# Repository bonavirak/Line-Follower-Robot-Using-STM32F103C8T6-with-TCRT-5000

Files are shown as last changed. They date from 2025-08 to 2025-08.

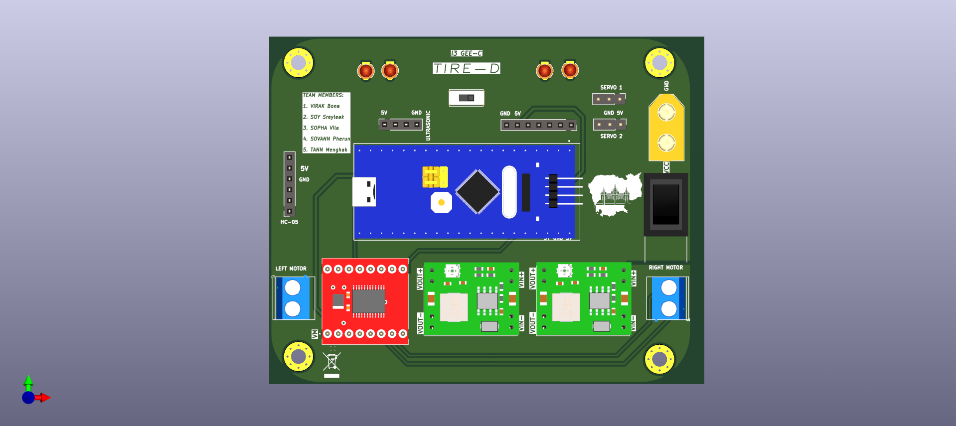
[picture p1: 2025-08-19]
LineFollowerPCB/fun.png

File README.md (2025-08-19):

# Line Follower Robot with STM32F103C8T6 and TCRT5000

This Line Follower Robot, winner of Line Follwer Robot Competition 2025, was designed and developed by Bona Virak. The project uses an STM32F103C8T6 microcontroller, TCRT5000 5-way sensors, HC-05 Bluetooth module, TB6612FNG motor driver, and N20 motors (1000 RPM). It features two modes: Auto (PID-based line following with Case 0/Case 1 logic) and Manual (Bluetooth RC control via app).

## Credits
- **Author**: [Bona Virak](https://github.com/bonavirak) - Sole developer of the code, PCB design, and implementation.
- **Team**: Tire-d - Acknowledged for participation in Line Follwer Robot Competition 2025, with minimal contributions.

## Features
- C-based firmware with PID control for auto mode line following.
- Manual mode for Bluetooth RC car control via HC-05.
- PCB design (schematics, Gerber files, BOM) optimized for STM32 integration.
- Case-based navigation (Case 0 for straight paths, Case 1 for turns) in auto mode.

## Setup
### Hardware
1. **Components**:
   - STM32F103C8T6 microcontroller
   - TCRT5000 5-way sensor array
   - HC-05 Bluetooth module
   - TB6612FNG motor driver
   - 2x N20 motors (1000 RPM)
   - Power supply (e.g., 11.1V LiPo battery)
2. **Schematic**:
   - See schematic: 
3. **Wiring**:
- **Connect TCRT5000 Sensors to STM32**:
  - Pins: **PA0-PA4** 
- **Link HC-05 TX/RX to STM32**:
  - USART1: **PA9/PA10** (TX/RX) 
- **Attach TB6612FNG PWM/GPIO Pins to STM32**:
  - PWMA: **PB7**  (TIM4 CH2)
  - PWMB: **PB6**  (TIM4 CH1)
  - AI1: **PB12** 
  - AI2: **PB13** 
  - BI1: **PB14** 
  - BI2: **PB15** 
  - STBY: **PB1** 
  - VCC: **3.3V** 
- **Add Servo to STM32**:
  - PWM: **PB4** (TIM3 CH1) 
- **Wire N20 Motors to TB6612FNG Outputs**:
  - Power: **11.1V LiPo** 
- **Refer to Detailed Pin Assignments**:
  - Check out the epic diagram! 
   Pin Assignments

### Software
1. **Requirements**:
   - STM32CubeIDE for compiling C code.
   - ST-Link/V2 for flashing.
   - Bluetooth RC app (e.g., "Bluetooth RC Controller" on Android) for manual mode.
2. **Steps**:
   - Clone: git clone: https://github.com/bonavirak/STM32F103C8T6-Line-Follower-Robot-TCRT5000.git.
   - Open `/code/` in STM32CubeIDE.
   - Configure PID in `pid.c` (e.g., Kp=0.5, Ki=0.1, Kd=0.05) for auto mode.
   - Build/flash code to STM32F103C8T6 using ST-Link.
3. **Auto Mode**:
   - Test Case 0/Case 1 on sample map 
4. **Manual Mode**:
   - Pair HC-05 with Bluetooth RC app (default PIN: 1234 or 0000).
   - Use app to control motors (forward, backward, left, right).

## Demo
Watch the robot in action:
- **Video**: [Video demo will be added soon!]
- **Images**: [Soon!]
- **Description**: Auto mode uses PID control for line following (Case 0 for straight, Case 1 for turns). Manual mode allows RC car control via Bluetooth app, demonstrated in Line Follwer Robot Competition 2025 winning run.

## License
Licensed under the MIT License. See [LICENSE](LICENSE) for details.

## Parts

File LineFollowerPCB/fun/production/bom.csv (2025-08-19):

Designator | Footprint | Quantity | Value | LCSC Part #
C1, C3 | 0603 | 2 | 0.1uF
C2, C4 | 0603 | 2 | 10uF
D2, D3, D4, D5 | LED_D3.0mm | 4 | LED
H1, H2, H3, H4 | MountingHole_3.5mm_Pad_Via | 4 | MountingHole
HC1 | PinSocket_1x06_P2.54mm_Vertical | 1 | Conn_01x06_Female
J1 | AMASS_XT60-M_1x02_P7.20mm_Vertical | 1 | Screw_Terminal_01x02
J10, J6 | PinSocket_1x02_P2.54mm_Vertical | 2 | VIN+
J11, J8 | PinSocket_1x02_P2.54mm_Vertical | 2 | VIN-
J12, J7 | PinSocket_1x02_P2.54mm_Vertical | 2 | VOUT+
J13, J9 | PinSocket_1x02_P2.54mm_Vertical | 2 | VOUT-
J2 | TerminalBlock_Phoenix_MKDS-1,5-2_1x02_P5.00mm_Horizontal-(Large) | 1 | Left_Motor
J3 | TerminalBlock_Phoenix_MKDS-1,5-2_1x02_P5.00mm_Horizontal-(Large) | 1 | Right_Motor
J4 | PinSocket_1x04_P2.54mm_Vertical | 1 | ULTRASONIC
R2, R3, R4, R5 | 0603 | 4 | 220
SERVO1, SERVO2 | PinHeader_1x03_P2.54mm_Vertical | 2 | ~
SW1 | BarrelJack_SwitchcraftConxall_RAPC10U_Horizontal | 1 | SW_SPST
SW2 | PinHeader_1x03_P2.54mm_Vertical | 1 | SW_SPDT
TCRT1 | PinSocket_1x07_P2.54mm_Vertical | 1 | Conn_01x07_Female
U1 | MODULE_ROB-14450 | 1 | ROB-14450
U2 | STM32F103C8T6 | 1 | ZC323000

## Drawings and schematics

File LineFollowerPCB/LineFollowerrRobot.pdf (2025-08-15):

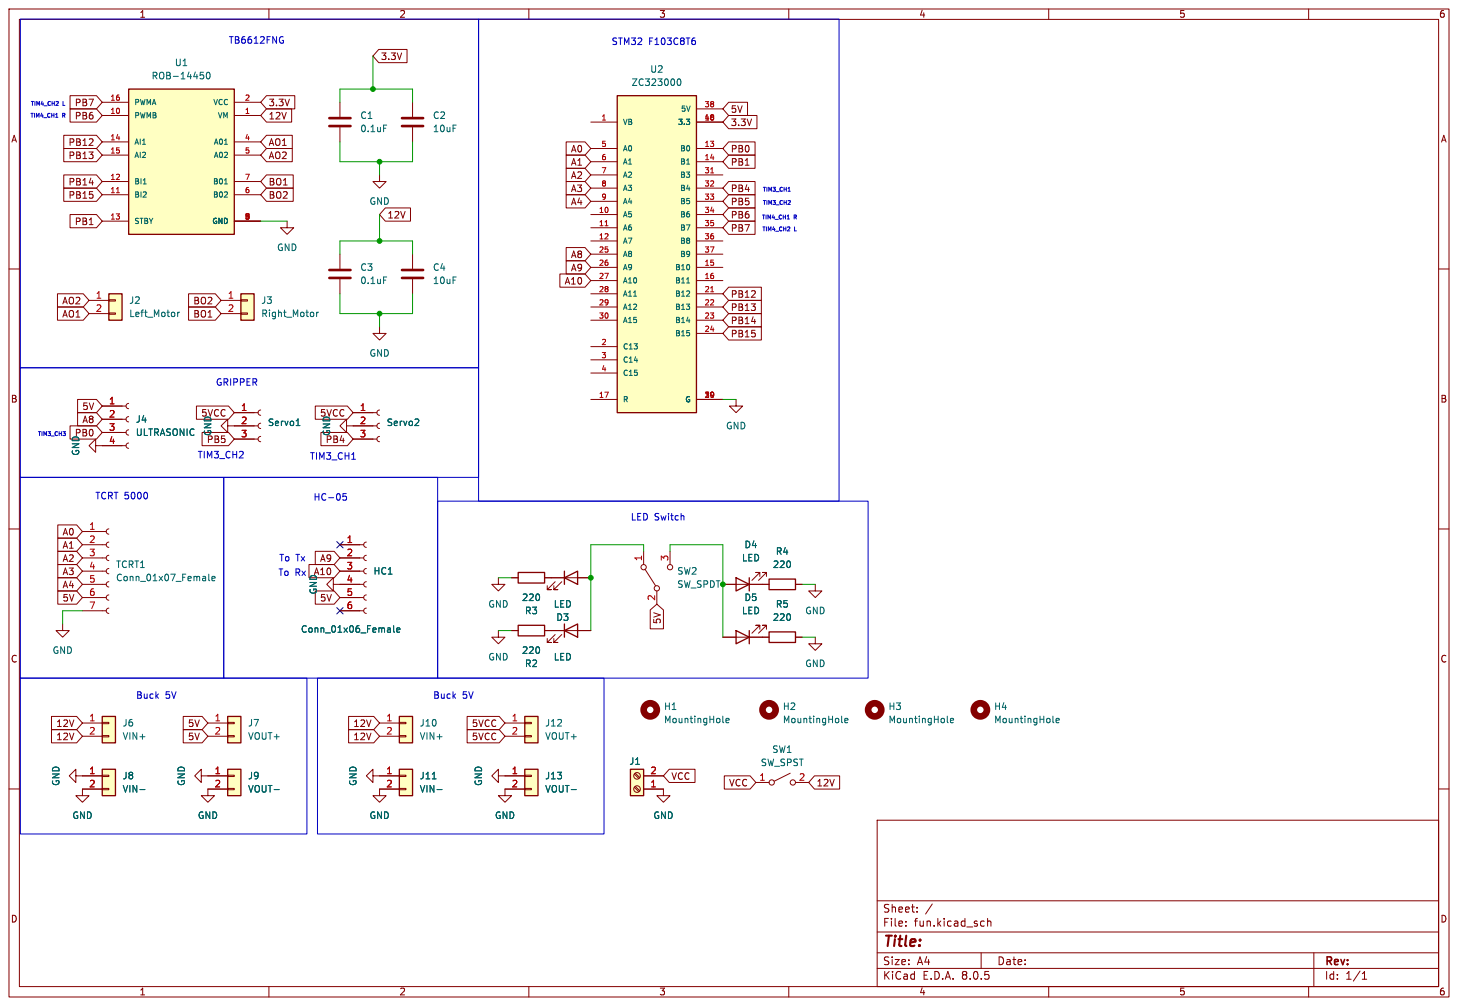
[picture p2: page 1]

LED
Id: 1/1 Title: File: fun.kicad_sch Sheet: / R3


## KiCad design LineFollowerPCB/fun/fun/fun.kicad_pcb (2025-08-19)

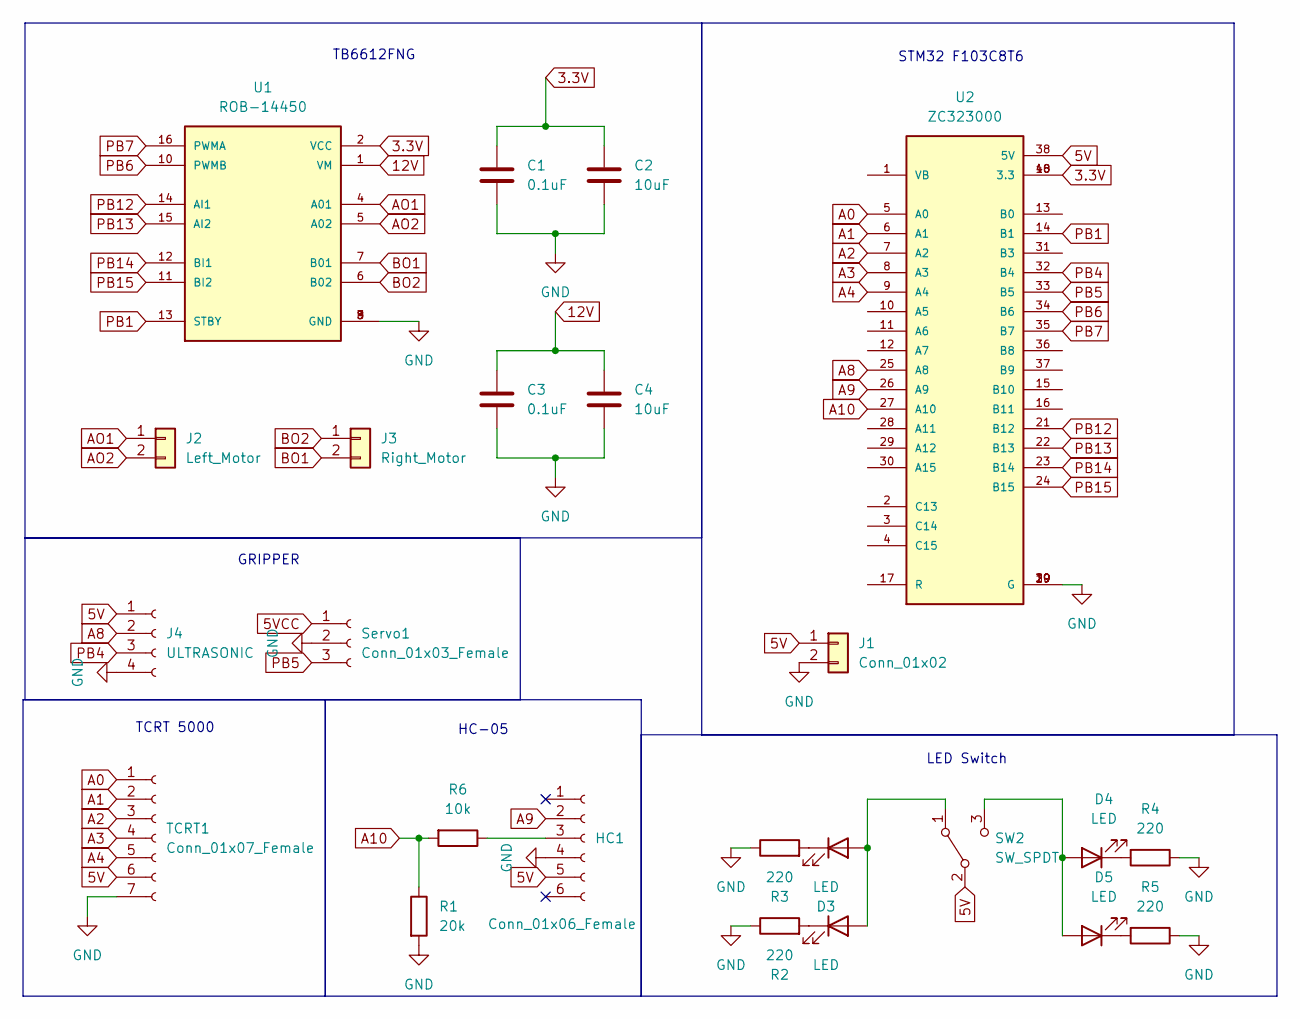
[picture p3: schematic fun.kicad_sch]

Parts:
C1, C3: 0.1uF; C_0603_1608Metric
C2, C4: 10uF; C_0603_1608Metric
D2, D3, D4, D5: LED; LED_D3.0mm
HC1: Conn_01x06_Female; PinSocket_1x06_P2.54mm_Vertical
J1: Conn_01x02; PinSocket_1x02_P2.54mm_Vertical
J2: Left_Motor; PinSocket_1x02_P2.54mm_Vertical
J3: Right_Motor; PinSocket_1x02_P2.54mm_Vertical
J4: ULTRASONIC; PinSocket_1x04_P2.54mm_Vertical
R1: 20k; R_0201_0603Metric
R2, R3, R4, R5: 220; R_0201_0603Metric
R6: 10k; R_0201_0603Metric
SW2: SW_SPDT; PinHeader_1x03_P2.54mm_Vertical
Servo1: Conn_01x03_Female; PinSocket_1x03_P2.54mm_Vertical
TCRT1: Conn_01x07_Female; PinSocket_1x07_P2.54mm_Vertical
U1: ROB-14450; MODULE_ROB-14450; PARTREV 11-13-17
U2: ZC323000; STM32F103C8T6; PARTREV N/A

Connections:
3.3V: C1.1, C2.1, U1.2 (VCC), U2.18 (3.3), U2.40 (3.3)
5V: HC1.5, J1.1, J4.1, SW2.2 (B), TCRT1.6, U2.38 (5V)
5VCC: Servo1.1
12V: C3.1, C4.1, U1.1 (VM)
A0: TCRT1.1, U2.5 (A0)
A1: TCRT1.2, U2.6 (A1)
A2: TCRT1.3, U2.7 (A2)
A3: TCRT1.4, U2.8 (A3)
A4: TCRT1.5, U2.9 (A4)
A8: J4.2, U2.25 (A8)
A9: HC1.2, U2.26 (A9)
A10: R1.1, R6.2, U2.27 (A10)
AO1: J2.1, U1.4 (A01)
AO2: J2.2, U1.5 (A02)
BO1: J3.2, U1.7 (B01)
BO2: J3.1, U1.6 (B02)
GND: C1.2, C2.2, C3.2, C4.2, HC1.4, J1.2, J4.4, R1.2, R2.1, R3.1, R4.1, R5.1, Servo1.2, TCRT1.7, U1.3 (GND), U1.8 (GND), U1.9 (GND), U2.19 (G), U2.20 (G), U2.39 (G)
unnamed: D2.2 (A), D3.2 (A), SW2.1 (A)
unnamed: D2.1 (K), R2.2
unnamed: D3.1 (K), R3.2
unnamed: D4.2 (A), D5.2 (A), SW2.3 (C)
unnamed: D4.1 (K), R4.2
unnamed: D5.1 (K), R5.2
unnamed: HC1.3, R6.1
PB1: U1.13 (STBY), U2.14 (B1)
PB4: J4.3, U2.32 (B4)
PB5: Servo1.3, U2.33 (B5)
PB6: U1.10 (PWMB), U2.34 (B6)
PB7: U1.16 (PWMA), U2.35 (B7)
PB12: U1.14 (AI1), U2.21 (B12)
PB13: U1.15 (AI2), U2.22 (B13)
PB14: U1.12 (BI1), U2.23 (B14)
PB15: U1.11 (BI2), U2.24 (B15)

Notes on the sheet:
GRIPPER
LED Switch
HC-05
TB6612FNG
STM32 F103C8T6
TCRT 5000

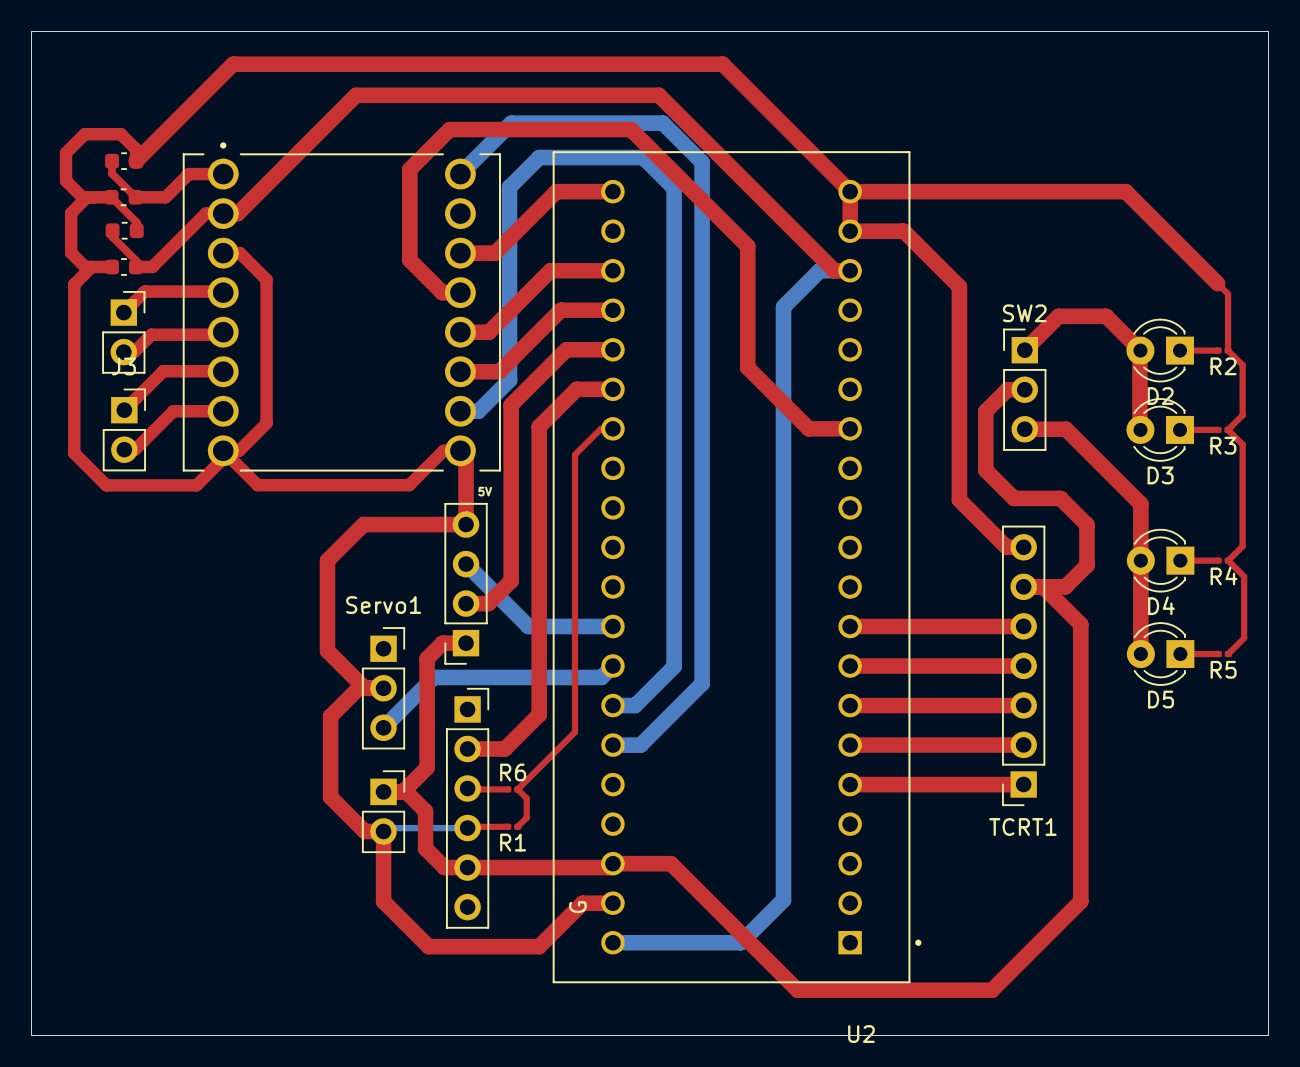
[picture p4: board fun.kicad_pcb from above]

Board: 2 copper layers, 79.5 x 64.5 mm, 24 parts (0 on the bottom side), 32 nets.

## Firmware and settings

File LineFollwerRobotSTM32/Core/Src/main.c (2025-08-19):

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
/* Includes ------------------------------------------------------------------*/
#include "main.h"

/* USER CODE BEGIN Includes */
#include <math.h>

/* USER CODE END Includes */

/* USER CODE BEGIN PD */
#define SENSOR_COUNT 5
#define MAX_SPEED 100    // Maximum speed
/* USER CODE END PD */

TIM_HandleTypeDef htim2;
TIM_HandleTypeDef htim3;
TIM_HandleTypeDef htim4;

UART_HandleTypeDef huart1;

/* USER CODE BEGIN PV */
int weights[5] = {-4, -2, 0, 2, 4}; // Define weights (in mm) for 5 sensors: left to right
float Kp = 2.5;                     // Proportional gain
float Ki = 0.001;                     // Integral gain
float Kd = 0.5;                    // Derivative gain
float dt = 0.005;                   // Time delta (seconds) — adjust to your system
float d = 10.0;                     // Distance between position readings (in mm)
float previous_error = 0;           // Previous error for derivative control
float integral = 0;                 // Accumulated error for integral control
float previous_position = 0;        // Previous position for heading angle
int intersection_count=0;
int grab_count=0;
int has_grabbed = 0; // Global flag to track if grab has occurred
int current_case = 0; // 0 = Case 0, 1 = Case 1, 2 = Case 2, etc.
int sensor_count = 0; // Count how many times all 5 sensors are detected in Case 1

uint8_t sensor_values[SENSOR_COUNT]; // Array to store sensor readings

float x =0;//lateral position
float u =0; //control output
int pwmL =0;
int pwmR=0;
int basespeed=0;

int j=0; // Line-loss

// UART-related variables
uint8_t rx_data;         // Received UART data
uint8_t last_command = 0;// Last received command

uint8_t uto = 'U';       // Mode control: 'U' for auto, 'u' for manual
char grip = 0;           // Gripper state: 'W' for close, 'w' for open
int speed_level = 7;     // Speed level (0-9) for manual mode

static int case1_delay_count = 0;
static int case2_stopped = 0;
static int case2_ignore_count = 0;
static int case2_post_stop_state = 0;
static int case2_post_action_count = 0;
static int case3_has_grabbed = 0;
static int turn_state = 0;
static int turn_count = 0;
static int case3_stopped = 0;
static int case3_ignore_count = 0;
static int case3_post_stop_state = 0;
static int case3_post_action_count = 0;

int caseF_active = 0;     // Flag to track if CaseF is active
int caseF_end_condition = 0; // Flag to track when CaseF should end

// New global variables for Case0 forward push
int case0_initial_push_count = 0; // Counter for initial forward push in Case0
int case0_initial_push_done = 0;  // Flag to track if initial push is complete in Case0

// New global variable for Case1 forward push
int case1_push_after_grab_done = 0; // Flag to track if forward push after grab is done

// New global variable for Case3 forward push
int case3_push_after_grab_count = 0; // Counter for forward push after grab in Case3

int case2_reset_active = 0; // Flag to track if Case2Reset is active


/* USER CODE END PV */

void SystemClock_Config(void);
static void MX_GPIO_Init(void);
static void MX_TIM4_Init(void);
static void MX_USART1_UART_Init(void);
static void MX_TIM3_Init(void);
static void MX_TIM2_Init(void);
/* USER CODE BEGIN PFP */
void set_left_motor(int speed);
void set_right_motor(int speed);
void read_sensors();
float compute_position();
float compute_pid(float error);
float compute_heading(float x_now);
void Set_Servo_Angle(uint8_t angle);
void motor_ctr(int speedL, int speedR);
void followLine(void);
void followLine_Case0(void);
void followLine_Case1(void);
void followLine_Case2(void);
void followLine_Case3(void);
/* USER CODE END PFP */

/* USER CODE BEGIN 0 */
void Set_Servo_Angle(uint8_t angle)
{
  // Map 0–180° to 500–2500us (pulse width in timer counts)
  uint16_t pulse_width = 500 + ((angle * 2000) / 180);
  __HAL_TIM_SET_COMPARE(&htim3, TIM_CHANNEL_1, pulse_width);  // Set PWM pulse width
}

/* USER CODE END 0 */

/**
  * @brief  The application entry point.
  * @retval int
  */
int main(void)
{

  /* MCU Configuration--------------------------------------------------------*/

  /* Reset of all peripherals, Initializes the Flash interface and the Systick. */
  HAL_Init();

  /* Configure the system clock */
  SystemClock_Config();

  /* Initialize all configured peripherals */
  MX_GPIO_Init();
  MX_TIM4_Init();
  MX_USART1_UART_Init();
  MX_TIM3_Init();
  MX_TIM2_Init();
  /* USER CODE BEGIN 2 */
  HAL_TIM_PWM_Start(&htim4, TIM_CHANNEL_1);
  HAL_TIM_PWM_Start(&htim4, TIM_CHANNEL_2);
  HAL_TIM_PWM_Start(&htim3, TIM_CHANNEL_1); // Start PWM for servo

  HAL_TIM_Base_Start_IT(&htim2);
  HAL_UART_Receive_IT(&huart1, &rx_data, 1); // Enable UART interrupt
  HAL_GPIO_WritePin(GPIOB, GPIO_PIN_1, 1);
  /* USER CODE END 2 */

  /* Infinite loop */
  /* USER CODE BEGIN WHILE */
  while (1)
  {
    /* USER CODE END WHILE */

    /* USER CODE BEGIN 3 */
  }
  /* USER CODE END 3 */
}

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
/* USER CODE BEGIN 4 */
/**
  * @brief Set speed and direction for the left motor
  * @param speed: Speed value (-95 to 95). Positive for forward, negative for backward.
  * @retval None
  */
void set_left_motor(int speed)
{
  speed = (speed > MAX_SPEED) ? MAX_SPEED : (speed < -MAX_SPEED/2) ? -MAX_SPEED/2 : speed;
  TIM4->CCR2 = (speed >= 0) ? (uint32_t)speed : (uint32_t)(-speed);
  HAL_GPIO_WritePin(GPIOB, GPIO_PIN_12, (speed > 0) ? GPIO_PIN_SET : GPIO_PIN_RESET);
  HAL_GPIO_WritePin(GPIOB, GPIO_PIN_13, (speed < 0) ? GPIO_PIN_SET : GPIO_PIN_RESET);
}

/**
  * @brief Set speed and direction for the right motor
  * @param speed: Speed value (-95 to 95). Positive for forward, negative for backward.
  * @retval None
  */
void set_right_motor(int speed)
{
  speed = (speed > MAX_SPEED) ? MAX_SPEED : (speed < -MAX_SPEED/2) ? -MAX_SPEED/2 : speed;
  TIM4->CCR1 = (speed >= 0) ? (uint32_t)speed : (uint32_t)(-speed);
  HAL_GPIO_WritePin(GPIOB, GPIO_PIN_14, (speed > 0) ? GPIO_PIN_SET : GPIO_PIN_RESET);
  HAL_GPIO_WritePin(GPIOB, GPIO_PIN_15, (speed < 0) ? GPIO_PIN_SET : GPIO_PIN_RESET);
}

void motor_ctr(int speedL, int speedR)
{
  set_right_motor(speedR);
  set_left_motor(speedL);
}

/**
  * @brief Read sensor states
  * @retval None
  */
void read_sensors(void)
{
  sensor_values[0] = !HAL_GPIO_ReadPin(GPIOA, GPIO_PIN_0);
  sensor_values[1] = !HAL_GPIO_ReadPin(GPIOA, GPIO_PIN_1);
  sensor_values[2] = !HAL_GPIO_ReadPin(GPIOA, GPIO_PIN_2);
  sensor_values[3] = !HAL_GPIO_ReadPin(GPIOA, GPIO_PIN_3);
  sensor_values[4] = !HAL_GPIO_ReadPin(GPIOA, GPIO_PIN_4);

  if (sensor_values[0] == 1) {
    j = 1;
  }
  else if (sensor_values[4] == 1) {
    j = 2;
  }

  if (j == 1) {
    sensor_values[0] = 1;
  }
  else if (j == 2) {
    sensor_values[4] = 1;
  }
  if (sensor_values[1] == 1 || sensor_values[2] == 1 || sensor_values[3] == 1) {
    j = 0;
  }
}

/**
  * @brief Compute lateral position
  * @retval float: Position in mm
  */
float compute_position()
{
  int sum_s = 0;
  int weighted_sum = 0;

  for (int i = 0; i < 5; i++) {
    sum_s += sensor_values[i];
    weighted_sum += sensor_values[i] * weights[i];
  }

  if (sum_s == 0)
    return 0.0; // No line detected, assume center or trigger fail-safe

  return (float)weighted_sum / sum_s;
}

/**
  * @brief Compute PID control output
  * @param error: Current error
  * @retval float: PID control output
  */
float compute_pid(float error)
{
  integral += error * dt;
  float derivative = (error - previous_error) / dt;
  float output = Kp * error + Ki * integral + Kd * derivative;
  previous_error = error;
  return output;
}

/**
  * @brief Compute heading angle
  * @param x_now: Current position
  * @retval float: Heading angle in radians
  */
float compute_heading(float x_now)
{
  float Q = (x_now - previous_position) / d;
  previous_position = x_now;
  return Q; // in radians (approximation)
}

void followLine(void)
{
  x = compute_position();
  u = compute_pid(x);
  if (fabs(x) < 1) {
    basespeed = 55;
  }
  else if (fabs(x) <= 2) {
    basespeed = 40;
  }
  else if (fabs(x) <= 4) {
    basespeed = 20;
  }
  pwmL = basespeed + u;
  pwmR = basespeed - u;
  motor_ctr(pwmL, pwmR);
}

void followLine_Case0(void)
{


	Set_Servo_Angle(40);

	// Step 2: Initial forward push for 200ms (40 cycles at 5ms)
	    if (!case0_initial_push_done) {
	        pwmL = 50; // Fixed speed for forward push
	        pwmR = 50;
	        motor_ctr(pwmL, pwmR);
	        case0_initial_push_count++;
	        if (case0_initial_push_count >= 40) { // 200ms / 5ms = 40 cycles
	            case0_initial_push_done = 1; // Mark push as complete
	            case0_initial_push_count = 0; // Reset counter for potential reuse
	        }
	        return; // Exit function until push is complete
	    }

  x = compute_position();
  u = compute_pid(x);
  if (fabs(x) < 1) {
    basespeed = 55;
  } else if (fabs(x) <= 2) {
    basespeed = 37;
  } else if (fabs(x) <= 4) {
    basespeed = 25
    		;
  }

  int sensor_sum = sensor_values[0] + sensor_values[1] + sensor_values[2] + sensor_values[3] + sensor_values[4];
  if (!has_grabbed) {
    if (sensor_values[0] == 1 && sensor_values[1] == 1 && sensor_values[2] == 1 && sensor_values[3] == 1) {
      Set_Servo_Angle(0); // Grab to 0°
      has_grabbed = 1;    // Prevent further servo commands
      current_case = 1;
    } else if (sensor_values[4] == 1 && sensor_values[3] == 1 && sensor_values[2] == 1 && sensor_values[1] == 1) {
      Set_Servo_Angle(0); // Grab to 0°
      has_grabbed = 1;    // Prevent further servo commands
      current_case = 1;
    } else if (sensor_sum == 5 && sensor_values[2] == 1) { // Ensure center sensor is off too
      Set_Servo_Angle(0); // Grab to 0°
      has_grabbed = 1;    // Prevent further servo commands
      current_case = 1;
    }
  }

  pwmL = basespeed + u;
  pwmR = basespeed - u;
  motor_ctr(pwmL, pwmR);
}

void followLine_Case1(void)
{

  // Set new PID values for Case 1
  Kp = 15;
  Ki = 0.0;
  Kd = 0.0;
  // Reset PID state
  integral = 0;
  previous_error = 0;

  // Step 1: Forward push for 200ms (40 cycles at 5ms) after grabbing
      if (!case1_push_after_grab_done) {
          if (case1_delay_count < 110) {
              pwmL = 30; // Fixed speed for forward push
              pwmR = 30;
              motor_ctr(pwmL, pwmR);
              case1_delay_count++;
              return; // Exit until push is complete
          } else {
              case1_push_after_grab_done = 1; // Mark push as complete
              case1_delay_count = 0; // Reset counter for next phase
          }
      }

  x = compute_position();
  u = compute_pid(x);
  if (fabs(x) < 1) {
    basespeed = 40;
  } else if (fabs(x) <= 2) {
    basespeed = 38;
  } else if (fabs(x) <= 4) {
    basespeed = 40;
  }

  int sensor_sum = sensor_values[0] + sensor_values[1] + sensor_values[2] + sensor_values[3] + sensor_values[4];

  // Ignore sensor_sum == 5 for 500ms (100 cycles * 5ms)
  if (case1_delay_count < 100) {
	  case1_delay_count++;
  } else if (sensor_sum == 4) {
    current_case = 2;  // Move to Case 2 when all sensors detect the line
  }

  pwmL = basespeed + u;
  pwmR = basespeed - u;
  motor_ctr(pwmL, pwmR);
}

// Modified followLine_Case2 function
void followLine_Case2(void)
{
  if (!case2_stopped) {
    Kp = 2.5;
    Ki = 0.0;
    Kd = 0.0;
    integral = 0;
    previous_error = 0;

    x = compute_position();
    u = compute_pid(x);
    if (fabs(x) < 1) {
      basespeed = 40;
    } else if (fabs(x) <= 2) {
      basespeed = 40;
    } else if (fabs(x) <= 4) {
      basespeed = 40;
    }

    int sensor_sum = sensor_values[0] + sensor_values[1] + sensor_values[2] + sensor_values[3] + sensor_values[4];

    if (case2_ignore_count < 40) {
      case2_ignore_count++;
      pwmL = basespeed + u;
      pwmR = basespeed - u;
      motor_ctr(pwmL, pwmR);
    } else {
      if (sensor_sum == 5 && !case2_stopped) {
        case2_stopped = 1;
        pwmL = 0;
        pwmR = 0;
        motor_ctr(pwmL, pwmR);
        case2_post_stop_state = 1;
        case2_post_action_count = 0;
      } else if (!case2_stopped) {
        pwmL = basespeed + u;
        pwmR = basespeed - u;
        motor_ctr(pwmL, pwmR);
      }
    }
  } else {
    if (case2_post_stop_state == 1) {
      pwmL = 25;
      pwmR = 25;
      motor_ctr(pwmL, pwmR);
      case2_post_action_count++;
      if (case2_post_action_count >= 70) {
        case2_post_stop_state = 2;
        case2_post_action_count = 0;
        pwmL = 0;
        pwmR = 0;
        motor_ctr(pwmL, pwmR);
      }
    } else if (case2_post_stop_state == 2) {
      Set_Servo_Angle(40);
      case2_post_action_count++;
      if (case2_post_action_count >= 20) {
        case2_post_stop_state = 3;
        case2_post_action_count = 0;
      }
    } else if (case2_post_stop_state == 3) {
      pwmL = -35;
      pwmR = -35;
      motor_ctr(pwmL, pwmR);
      case2_post_action_count++;
      if (case2_post_action_count >= 145) {
        case2_post_stop_state = 4;
        case2_post_action_count = 0;
        pwmL = 0;
        pwmR = 0;
        motor_ctr(pwmL, pwmR);
      }
    } else if (case2_post_stop_state == 4) {
      pwmL = 70;
      pwmR = 30;
      motor_ctr(pwmL, pwmR);
      case2_post_action_count++;
      if (case2_post_action_count >= 100) {
        case2_post_stop_state = 5;
        current_case = 3;
        pwmL = 0;
        pwmR = 0;
        motor_ctr(pwmL, pwmR);
      }
    }
  }
}

void followLine_Case2Reset(void)
{
//	Set_Servo_Angle(0);
  if (!case2_stopped) {
    Kp = 2.5;
    Ki = 0.0;
    Kd = 0.0;
    integral = 0;
    previous_error = 0;

    x = compute_position();
    u = compute_pid(x);
    if (fabs(x) < 1) {
      basespeed = 40;
    } else if (fabs(x) <= 2) {
      basespeed = 40;
    } else if (fabs(x) <= 4) {
      basespeed = 40;
    }

    int sensor_sum = sensor_values[0] + sensor_values[1] + sensor_values[2] + sensor_values[3] + sensor_values[4];

    if (case2_ignore_count < 50) {
      case2_ignore_count++;
      pwmL = basespeed + u;
      pwmR = basespeed - u;
      motor_ctr(pwmL, pwmR);
    } else {
      if (sensor_sum == 5 && !case2_stopped) {
        case2_stopped = 1;
        pwmL = 0;
        pwmR = 0;
        motor_ctr(pwmL, pwmR);
        case2_post_stop_state = 1;
        case2_post_action_count = 0;
      } else if (!case2_stopped) {
        pwmL = basespeed + u;
        pwmR = basespeed - u;
        motor_ctr(pwmL, pwmR);
      }
    }
  } else {
    if (case2_post_stop_state == 1) {
      pwmL = 25;
      pwmR = 25;
      motor_ctr(pwmL, pwmR);
      case2_post_action_count++;
      if (case2_post_action_count >= 70) {
        case2_post_stop_state = 2;
        case2_post_action_count = 0;
        pwmL = 0;
        pwmR = 0;
        motor_ctr(pwmL, pwmR);
      }
    } else if (case2_post_stop_state == 2) {
      Set_Servo_Angle(40);
      case2_post_action_count++;
      if (case2_post_action_count >= 20) {
        case2_post_stop_state = 3;
        case2_post_action_count = 0;
      }
    } else if (case2_post_stop_state == 3) {
      pwmL = -30;
      pwmR = -30;
      motor_ctr(pwmL, pwmR);
      case2_post_action_count++;
      if (case2_post_action_count >= 145) {
        case2_post_stop_state = 4;
        case2_post_action_count = 0;
        pwmL = 0;
        pwmR = 0;
        motor_ctr(pwmL, pwmR);
      }
    } else if (case2_post_stop_state == 4) {
      pwmL = 20;
      pwmR = -35;
      motor_ctr(pwmL, pwmR);
      case2_post_action_count++;
      if (case2_post_action_count >= 110) {
        case2_post_stop_state = 5;

        // Transition to Case 3 and reset Case2Reset flag
        current_case = 3;
        case2_reset_active = 0; // Clear the Case2Reset flag

        // Reset Case3 variables for fresh start
        case3_has_grabbed = 0;
        case3_push_after_grab_count = 0;

        pwmL = 0;
        pwmR = 0;
        motor_ctr(pwmL, pwmR);
      }
    }
  }
}
void followLine_Case3(void)
{
    if (!case3_stopped) {
        // Set PID values for normal line following
        Kp = 15;
        Ki = 0.0;
        Kd = 0.0;
        integral = 0;
        previous_error = 0;

        x = compute_position();
        u = compute_pid(x);
        if (fabs(x) < 1) {
            basespeed = 35;
        } else if (fabs(x) <= 2) {
            basespeed = 38;
        } else if (fabs(x) <= 4) {
            basespeed = 35;
        }

        int sensor_sum = sensor_values[0] + sensor_values[1] + sensor_values[2] + sensor_values[3] + sensor_values[4];

        // Ignore initial sensor readings for 250ms (50 cycles * 5ms)
        if (case3_ignore_count < 50) {
            case3_ignore_count++;
            pwmL = basespeed + u;
            pwmR = basespeed - u;
            motor_ctr(pwmL, pwmR);
        } else {
            // Check for 4 sensors detection after ignore period
            if (sensor_sum == 4 && !case3_stopped) {
                case3_stopped = 1;
                pwmL = 0;
                pwmR = 0;
                motor_ctr(pwmL, pwmR);
                case3_post_stop_state = 1;
                case3_post_action_count = 0;
            } else if (!case3_stopped) {
                // Continue normal line following
                pwmL = basespeed + u;
                pwmR = basespeed - u;
                motor_ctr(pwmL, pwmR);
            }
        }
    } else {
        // Handle post-stop actions sequentially
        if (case3_post_stop_state == 1) {
            // State 1: Brief stop for 100ms (20 cycles * 5ms)
            pwmL = 0;
            pwmR = 0;
            motor_ctr(pwmL, pwmR);
            case3_post_action_count++;
            if (case3_post_action_count >= 20) {
                case3_post_stop_state = 2;
                case3_post_action_count = 0;
            }
        } else if (case3_post_stop_state == 2) {
            // State 2: Left turn for 125ms (25 cycles * 5ms)
            pwmL = -35; // Left motor backward
            pwmR = 20;  // Right motor forward
            motor_ctr(pwmL, pwmR);
            case3_post_action_count++;
            if (case3_post_action_count >= 100) {
                case3_post_stop_state = 3;
                case3_post_action_count = 0;
            }
        } else if (case3_post_stop_state == 3) {
            // State 3: Final stop and transition to Case 4
            pwmL = 0;
            pwmR = 0;
            motor_ctr(pwmL, pwmR);
            case3_post_action_count++;
            if (case3_post_action_count >= 10) { // Brief final stop
                // Transition to Case 4
                current_case = 4;

                // Reset Case3 variables for potential future use
                case3_stopped = 0;
                case3_ignore_count = 0;
                case3_post_stop_state = 0;
                case3_post_action_count = 0;

                // Stop motors
                pwmL = 0;
                pwmR = 0;
                motor_ctr(pwmL, pwmR);
            }
        }
    }
}
void followLine_Case4(void)
{
    // Set new PID values for Case4
    Kp = 10;
    Ki = 0.0;
    Kd = 0.0;
    integral = 0;
    previous_error = 0;

    x = compute_position();
    u = compute_pid(x);
    if (fabs(x) < 1) {
        basespeed = 35; // Slower base speed
    } else if (fabs(x) <= 2) {
        basespeed = 35;
    } else if (fabs(x) <= 4) {
        basespeed = 35;
    }

    static int grab_state = 0;
    static int forward_count = 0;

    if (grab_state == 0) {
        int sensor_sum = sensor_values[0] + sensor_values[1] + sensor_values[2] + sensor_values[3] + sensor_values[4];
        if (sensor_sum == 5) {
            Set_Servo_Angle(0); // Grab
            grab_state = 1;
            forward_count = 0;
            pwmL = 20; // Start slow forward
            pwmR = 20;
        } else {
            pwmL = basespeed + u;
            pwmR = basespeed - u;
        }
    } else if (grab_state == 1) {
        pwmL = 30; // Slow forward
        pwmR = 30;
        motor_ctr(pwmL, pwmR);
        forward_count++;
        if (forward_count >= 500) { // 2 seconds (400 cycles * 5ms)
            grab_state = 2;
            pwmL = 0;
            pwmR = 0;
        }
    } else {
        pwmL = 0;
        pwmR = 0;
    }

    motor_ctr(pwmL, pwmR);
}

/* Complete the followLine_CaseF function */
void followLine_CaseF(void){
    // Set PID values for CaseF
    Kp = 18;
    Ki = 0.0;
    Kd = 0.0;
    integral = 0;
    previous_error = 0;

    // Read sensors and compute position
    x = compute_position();
    u = compute_pid(x);

    // Set speed based on position error
    if (fabs(x) < 1) {
        basespeed = 40;
    } else if (fabs(x) <= 2) {
        basespeed = 38;
    } else if (fabs(x) <= 4) {
        basespeed = 40;
    }

    // Calculate motor speeds
    pwmL = basespeed + u;
    pwmR = basespeed - u;
    motor_ctr(pwmL, pwmR);

    // Example end condition: when all sensors detect line (you can modify this)
    int sensor_sum = sensor_values[0] + sensor_values[1] + sensor_values[2] + sensor_values[3] + sensor_values[4];
    if (sensor_sum == 5) {
        caseF_end_condition = 1;  // Set flag to end CaseF
    }

    // Or add other end conditions as needed
    // For example, if no line is detected for a certain time:
    // if (sensor_sum == 0) {
    //     caseF_end_condition = 1;
    // }
}
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

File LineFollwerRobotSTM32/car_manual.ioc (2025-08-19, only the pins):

Mcu.UserName=STM32F103C8Tx
PA0-WKUP.Signal=GPIO_Input
PA1.Signal=GPIO_Input
PA10.Signal=USART1_RX
PA13.Signal=SYS_JTMS-SWDIO
PA14.Signal=SYS_JTCK-SWCLK
PA2.Signal=GPIO_Input
PA3.Signal=GPIO_Input
PA4.Signal=GPIO_Input
PA9.Signal=USART1_TX
PB1.Signal=GPIO_Output
PB12.Signal=GPIO_Output
PB13.Signal=GPIO_Output
PB14.Signal=GPIO_Output
PB15.Signal=GPIO_Output
PB4.Signal=S_TIM3_CH1
PB6.Signal=S_TIM4_CH1
PB7.Signal=S_TIM4_CH2
PC13-TAMPER-RTC.Signal=GPIO_Output
PD0-OSC_IN.Signal=RCC_OSC_IN
PD1-OSC_OUT.Signal=RCC_OSC_OUT

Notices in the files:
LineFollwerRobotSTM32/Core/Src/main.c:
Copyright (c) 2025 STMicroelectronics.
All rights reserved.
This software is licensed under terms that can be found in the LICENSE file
